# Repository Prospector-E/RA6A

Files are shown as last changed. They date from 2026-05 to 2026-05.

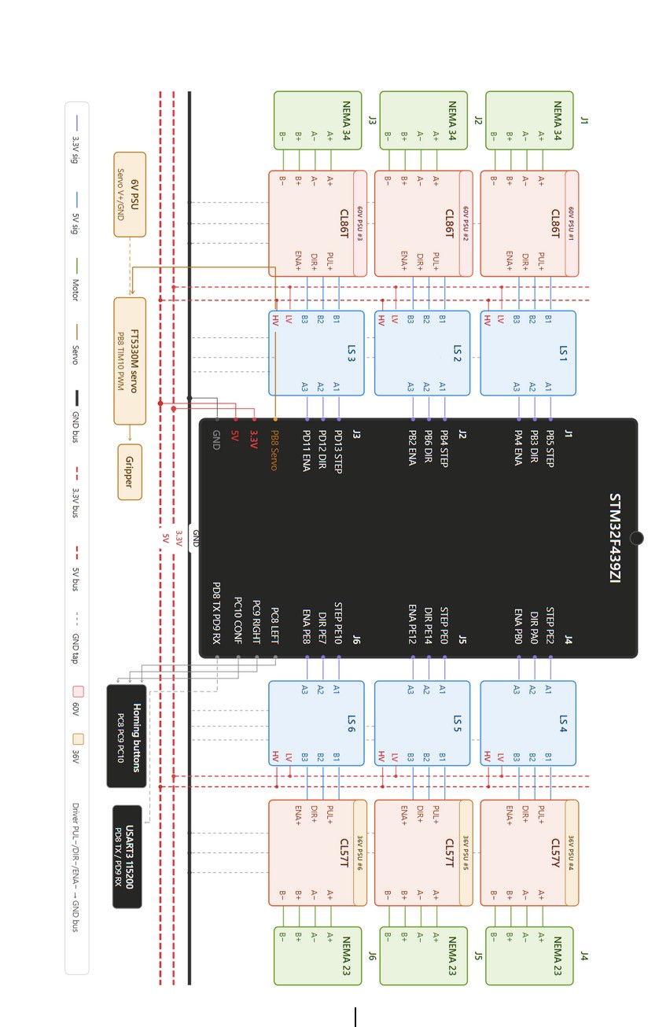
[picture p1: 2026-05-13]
images/wiring diagram.jpg

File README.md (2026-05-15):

# RA6A — 3D-Printed 6-Axis Robotic Arm

📺 **Demo:** https://youtu.be/l62hkhJTfqE?si=eneqJugdLhpxHiAf

Design, construction, and control of a 6-axis robotic arm built around an STM32F439ZI microcontroller and ROS 2 Humble with MoveIt 2. Capable of pick-and-place operation with vision-based cube detection.

Contact me if you have any questions, I’d love to see what the community does with this.

-----

## ⚠️ Important Warnings — Read Before Building

### CAD files are incomplete and contain errors

The STEP files in `hardware/cad/` are a **work-in-progress reference**, not a finished build package. If you intend to replicate this arm, be aware of the following:

- **Idler pulleys are not modeled** — every belt-driven joint requires idler pulleys for proper belt tensioning and routing. These are **mandatory** for the arm to function. You must add them yourself based on your motor placement and belt length.
- **Joint 2 (shoulder) deflects under load** — the J2 mechanical design is structurally weak and visibly deflects when the arm extends or carries payload. The cantilever geometry concentrates stress at the joint, and PLA+ creep makes it worse over time. A replicator should reinforce J2 with metal brackets, redesign the joint with a thicker cross-section, or use a co-axial drive configuration instead of the offset design used here. This is a known unresolved issue and one of the biggest weaknesses of the current design.
- **Belts are not modeled** — HTD-5M timing belts are used throughout. Lengths must be measured from your physical build.
- **Many small errors exist** — incorrect tolerances on some bearing pockets, hole misalignments, missing fillets, and a few non-printable overhangs. Expect to fix issues as you print.
- **The gripper is not my design** — it’s adapted from the AR4 open-source arm by Chris Annin (Annin Robotics). The original AR4 gripper files are available at https://www.anninrobotics.com — see the Acknowledgements section.

If you’re replicating this design, treat the CAD as a starting point — you will need to do your own engineering review and modifications.

### Hardcoded configuration to change

Before running anything, update these values for your setup:

- **iPhone camera IP** in the vision scripts (default `192.168.100.206` — your network will assign a different one)
- **Serial port** for the STM32 (default `/dev/ttyACM0` on Linux)
- **Camera calibration file path** in `scripts/aruco_detect.py` and `scripts/cube_detector_node.py`
- **ArUco marker positions** in `MARKER_POSITIONS_BASE` — these are measured from *my* workspace; you must re-measure them for yours (see the calibration section below)
- **Table height** — `TABLE_Z` is hardcoded to `0.273` m (the height of my table surface above the robot’s `base_link` origin). You must measure your own table height and update this value in `scripts/aruco_detect.py`, `scripts/cube_detector_node.py`, and `scripts/pick_and_place_vision.py`
- **Gripper length** — `GRASP_OFFSET` defaults to `0.10` m and is paired with a legacy fudge `Z_OFFSET_FIXED = -0.055` from my calibration. For a fresh build, **measure your real gripper length**, put that in `GRASP_OFFSET`, and set `Z_OFFSET_FIXED = 0`. See the Configuration section for details.
- **Gripper close angle** — `GRIP_CLOSE = 30` works for our 20 mm cubes and FT5330M servo. Different cubes or servos need recalibration; see the Configuration section.

-----

## Hardware Overview

|Component |Part |Notes |
|---|---|---|
|MCU |STM32F439ZI Nucleo-144 |Bare-metal firmware |
|J1–J3 motors |NEMA 34 stepper |High-torque base joints |
|J1–J3 drivers|CL86T closed-loop |60 V PSU each |
|J4–J6 motors |NEMA 23 stepper |Wrist joints |
|J4–J6 drivers|CL57T / CL57Y closed-loop|36 V PSU each |
|Gripper |FT5330M servo |**Adapted from AR4** — software PWM on PC11|
|Transmission |HTD-5M timing belts |Idler pulleys required (not in CAD) |
|Logic level  |3.3 V → 5 V shifter |Between STM32 and driver inputs |
|Structure |PLA+, 3D printed |Creality K2 Plus |

**Manual homing buttons:** LEFT (PC8), RIGHT (PC9), CONFIRM (PC10).

-----

## Software Architecture

```
┌─────────────────┐    plan trajectory    ┌────────────────────┐
│   MoveIt 2      │ ─────────────────────▶│  ra6a_hardware     │
│   (planning)    │                       │  (ROS 2 control)   │
└─────────────────┘                       └─────────┬──────────┘
                                                    │ 60 Hz serial
                                                    │ rosserial topics
                                                    ▼
                                          ┌─────────────────────┐
                                          │  STM32F439ZI        │
                                          │  - trapezoidal exec │
                                          │  - software PWM     │
                                          │  - manual homing    │
                                          └─────────────────────┘
```

MoveIt does all trajectory planning. The `ra6a_hardware` package forwards waypoints to the STM32 at 60 Hz over serial. The STM32 executes waypoints with trapezoidal velocity profiling and reports state back at 20 Hz.

**rosserial topic IDs:**

- `101` — joint command
- `102` — joint state feedback (20 Hz)
- `103` — homing complete
- `104` — motion complete
- `105` — gripper servo

-----

## Prerequisites

- Ubuntu 22.04 with ROS 2 Humble
- MoveIt 2 (`sudo apt install ros-humble-moveit`)
- `pick_ik` plugin (`sudo apt install ros-humble-pick-ik`)
- Python 3 with `opencv-python`, `numpy`, `pyserial`, `pyyaml`
- For firmware build: GCC ARM toolchain (`arm-none-eabi-gcc`), `make`
- DroidCam app on iPhone for vision pipeline (free version is enough)

-----

## Setup — Step by Step

### 1. Clone the repo

```bash
git clone https://github.com/Prospector-E/RA6A.git
cd RA6A
```

### 2. Build and flash STM32 firmware

The firmware is built with a Makefile — **no STM32CubeIDE required**.

```bash
cd firmware
make clean
make
```

This produces `build/ra6a.bin`. To flash, plug the Nucleo board into USB and copy the binary onto its mounted drive:

```bash
# Linux
cp build/ra6a.bin /media/$USER/NODE_F439ZI/

# Windows (in Git Bash)
cp build/ra6a.bin /x/      # replace /x/ with the Nucleo's drive letter
```

The board reflashes itself and resets automatically.

### 3. Build the ROS 2 workspace

```bash
cd ros2_ws
colcon build --symlink-install
source install/setup.bash
```

Add the source line to your `.bashrc` to avoid repeating it every terminal:

```bash
echo "source ~/RA6A/ros2_ws/install/setup.bash" >> ~/.bashrc
```

### 4. Update the serial port (if needed)

The STM32 typically appears as `/dev/ttyACM0`. Check with:

```bash
ls /dev/ttyACM*
```

If yours is different, update the `serial_port` parameter in `ros2_ws/src/ra6a_hardware/config/ra6a_hardware.yaml`.

Give your user permission to use serial without sudo:

```bash
sudo usermod -aG dialout $USER
# Log out and back in for it to take effect
```

-----

## Running the Arm

### 1. Manual homing (always first after power-up)

When the STM32 boots, all joints are at position zero in software but at arbitrary positions in reality. Home each joint manually:

1. Power on the arm.
1. Hold the **LEFT (PC8)** or **RIGHT (PC9)** button — the currently active joint moves in that direction.
1. Position the joint at its mechanical home reference.
1. Press **CONFIRM (PC10)** to save that position and advance to the next joint.
1. Repeat for all 6 joints.

Homed positions are saved to STM32 flash, so subsequent power-ups remember them. You only need to re-home if the arm is moved by hand or the flash is erased.

### 2. Launch MoveIt + hardware interface

```bash
ros2 launch ra6a_moveit_config servo.launch.py
```

This brings up MoveIt with the Servo plugin, RViz, and connects to the STM32 over serial. You should see the arm pose in RViz match the real arm.

### 3. Run pick-and-place

In a new terminal:

```bash
cd ~/RA6A/scripts
python3 pick_and_place_vision.py
```

The script runs the sequence: REST → PICK → grip → REST → PLACE → release → REST.

Edit the pick/place coordinates at the top of the script for your workspace.

-----

## Running the Vision Pipeline

The vision pipeline involves three calibration steps, done in this order:

1. **Camera intrinsics** — characterize the iPhone camera (lens distortion, focal length). One-time per camera.
1. **ArUco marker calibration** — tell the code where the table markers physically sit in the robot’s frame. Required for the camera-to-robot transform.
1. **Vision-to-arm calibration** — correct for residual systematic errors between detected cube positions and where the arm actually reaches. Optional but strongly recommended.

### 1. Set up DroidCam on iPhone

1. Install **DroidCam** from the App Store.
1. Connect the iPhone to the same WiFi as your Linux machine.
1. Open the app — note the IP address shown (e.g. `192.168.100.206`).
1. In settings, set resolution to 720p and lock exposure by tapping and holding on the workspace.

### 2. Update the IP in the scripts

The IP is hardcoded in three files (your iPhone’s IP will be different):

```bash
grep -rn "192.168" scripts/
```

Edit each file and change `IPHONE_IP = '192.168.100.206'` to your iPhone’s IP.

### 3. Camera intrinsics calibration (`calibrate_camera.py`)

This step measures the iPhone’s lens distortion and focal length using a printed checkerboard. The output is `camera_calibration.yaml`, which the detection scripts load. Done once per camera (or whenever you change cameras).

1. Print a checkerboard pattern on A4 paper. The defaults in the script are **9×6 inner corners** with **26 mm squares** — measure your printed squares and update `CHECKERBOARD` and `SQUARE_SIZE_M` constants if yours differ.
1. Tape it flat to a rigid board (so it doesn’t curl).
1. Run the script:
   
   ```bash
   python3 scripts/calibrate_camera.py
   ```
1. A live feed window opens. Hold the board in front of the iPhone — when the script detects the corners, they’re outlined in green.
1. Press **SPACE** to capture a frame. Capture 15–20 frames from different angles, distances, and positions (corners of frame, edges, close, far, tilted).
1. Press **Q** to compute and save `camera_calibration.yaml`.
1. Update `CALIB_FILE` paths in `aruco_detect.py` and `cube_detector_node.py` to point to wherever you saved it.

### 4. ArUco marker calibration (manual — must be done for your workspace)

The vision pipeline locates the iPhone camera in the robot’s frame by detecting four printed ArUco markers placed at known positions on the table. **You must physically measure each marker’s position relative to the robot’s `base_link` and update the code.** There is no automated procedure — this is a manual measurement step.

**Robot frame convention (`base_link`):**

- Origin is at the center of the robot’s base, on the bottom mounting surface
- **+X axis** points to the back of the robot (away from the front face)
- **+Y axis** points to the right (when standing behind the robot)
- **+Z axis** points up

**Setup procedure:**

1. **Print four ArUco markers**, **50 mm** each, with IDs **0, 1, 2, 3**. Use the same dictionary the code expects — check the `ARUCO_DICT` constant in `aruco_detect.py` (default `DICT_4X4_50`).
1. **Stick them flat on your table surface** at the corners of the workspace. They must be:
- **Flat** (no curling or tilt — back them with cardboard or stick to a rigid surface)
- **Visible to the iPhone camera** at all times
- **Spread out** (the further apart, the more accurate the camera pose solve)
- **Oriented consistently** — all four markers’ “up” direction the same way. This matters for the manual-corner calibration mode (see below).
1. **Measure the table height.** With a ruler or caliper, measure from the bottom of the robot’s base plate (the `base_link` origin Z = 0 plane) up to the top of the table surface. Record this value in **meters**. Example: 27.3 cm above the base → `TABLE_Z = 0.273`.
1. **Measure each marker’s center position** in the robot frame:
- Measure X (back/forward) and Y (right/left) of each marker’s center from the robot base origin.
- Z is the same as `TABLE_Z` for all four (they’re all on the table surface).
- Use **meters with signs**. Markers in front of the robot have negative X. Markers to the left of the robot have negative Y.
- Tip: stick a piece of tape on the table aligned with the robot’s center, run another tape strip out from the base for the X axis, and measure offsets from there.
1. **Update the constants** in both `scripts/aruco_detect.py` and `scripts/cube_detector_node.py`:
   
   ```python
   TABLE_Z = 0.273   # ← your measured table height (meters)
   
   MARKER_POSITIONS_BASE = {
       3: np.array([-0.370,  0.164, TABLE_Z]),   # ← your measured X, Y for marker 3
       2: np.array([-0.370, -0.268, TABLE_Z]),   # ← marker 2
       1: np.array([-0.190,  0.164, TABLE_Z]),   # ← marker 1
       0: np.array([-0.190, -0.268, TABLE_Z]),   # ← marker 0
   }
   ```
1. **Update the workspace bounds** in both files to match the rectangle bounded by your marker centres:
   
   ```python
   WORKSPACE_X_MIN, WORKSPACE_X_MAX = -0.370, -0.190    # min/max of marker X
   WORKSPACE_Y_MIN, WORKSPACE_Y_MAX = -0.268, +0.164    # min/max of marker Y
   ```
1. **Verify visually.** Run `python3 scripts/aruco_detect.py` — you should see the markers detected (green outlines) and the yellow workspace rectangle drawn on the table with its corners at the marker centres. Place a cube at a measured spot and check that the script’s reported position matches your ruler. If they disagree, your marker positions or `TABLE_Z` are off — re-measure.
1. **If your lighting is poor and ArUco auto-decode is flaky** — press `k` in the viewer and click each marker’s 4 corners (CW from each marker’s top-left, 16 clicks total). This saves to `~/manual_marker_corners.json` and the detector falls back to your manual corners whenever auto-decode fails. See the Configuration section below for full hotkey reference.

**Why this matters:** a 5 mm measurement error on a marker translates into noticeable end-effector offsets during pick attempts. Don’t eyeball it. Use a hard ruler or caliper and double-check signs.

### 5. Vision-to-arm calibration (`calibrate_vision.py`)

Even after camera intrinsics and ArUco calibration are done correctly, the position the camera reports for a cube and the position the arm actually reaches may still differ by a few millimeters or a small rotation, due to camera mount imperfection, base-frame misalignment, or small ArUco measurement errors. This script computes a 2D affine transform from “detected” to “real” coordinates and saves it to `~/vision_calibration.json`. The `pick_and_place_vision.py` script automatically loads and applies this transform.

**Strongly recommended.** Skipping this step usually results in pick attempts missing the cube by a few centimeters.

**Procedure:**

1. Place **three cubes** of different colors anywhere in the workspace (spread them out — corners of the workspace work best).
1. Start the supporting nodes in two separate terminals:
   
   ```bash
   # Terminal 1
   ros2 launch ra6a_moveit_config servo.launch.py
   
   # Terminal 2
   python3 scripts/cube_detector_node.py
   ```
1. In a third terminal, run the calibration script:
   
   ```bash
   python3 scripts/calibrate_vision.py
   ```
1. For each of the three cubes, the script prompts you to position the gripper:
- Use RViz’s interactive marker (plan + execute) to move the gripper **directly above the cube center**
- Gripper should point **straight down**
- Tip of the gripper jaws should be roughly **10 cm above the cube top**
- When the gripper is in position, press **SPACE** in the calibration terminal to record the pair (detected position, actual position)
1. After three pairs are recorded, the script computes the transform and saves `~/vision_calibration.json`. Done.
1. **Re-run this calibration whenever:**
- The iPhone is repositioned or remounted
- The robot is moved relative to the table
- The ArUco markers are repositioned
- Pick attempts start consistently missing in a systematic direction

### 6. Run vision-based pick-and-place

```bash
# Terminal 1: MoveIt + hardware
ros2 launch ra6a_moveit_config servo.launch.py

# Terminal 2: cube detector
python3 scripts/cube_detector_node.py

# Terminal 3: pick-and-place driver
python3 scripts/pick_and_place_vision.py
```

-----

## Configuration Variables and Tuning

This section is a reference for every tunable knob in the pipeline. Variables you *must* set for your hardware (table height, marker positions, camera IP) were covered above in workflow style; this section covers the rest — gripper geometry, servo angles, cube size, persisted JSON files, and viewer hotkeys.

### Gripper geometry — match these to your physical gripper

Set in `scripts/pick_and_place_vision.py`:

|Variable |Default |What it is |
|---|---|---|
|`GRASP_OFFSET`  |`0.10` m  |Distance from your URDF’s `end_effector` frame down to the grasp point (centre between closed jaws). Measure with a ruler. |
|`Z_OFFSET_FIXED`|`-0.055` m|Legacy fudge from my own calibration. **For a fresh build, leave this at `0` and just put your real measured gripper length in `GRASP_OFFSET`.** The grasp height equation is `TABLE_Z + CUBE_HEIGHT/2 + GRASP_OFFSET + Z_OFFSET_FIXED + GRASP_Z_ADJUST`, so the two `Z_OFFSET*` terms sum to your effective gripper length. Cleaner to use just one.|
|`GRASP_Z_ADJUST`|`+0.005` m|Fine-tune knob. Positive lifts the grip a bit higher (less risk of scraping the table); negative pushes deeper. Adjust in 1 mm steps after the rest is set. |
|`CUBE_HEIGHT` |`0.020` m |Edge length of your cubes. Used for both grasp height and to project the colour silhouette to mid-cube height. Change if your cubes aren’t 20 mm. |

### Gripper servo angles — calibrate to avoid stall

For servos with built-in overload/stall protection (e.g. FT5330M), you **cannot** command `GRIP_CLOSE = 0` on a cube that’s smaller than the gripper’s maximum closure. The servo will try, hit the cube, detect overcurrent, and back off — and your cube falls.

Set in `scripts/pick_and_place_vision.py`:

```python
GRIP_OPEN = 90      # fully open — usually fine at 90 for FT5330M-like servos
GRIP_CLOSE = 30     # just enough to grip your cube without stalling
```

**To calibrate `GRIP_CLOSE`:** start at `35`. Try a pick. If the cube wobbles or slides, lower to `30`. If you can hear the servo cycling or buzzing, back off by `5`. The right value is the *highest* one that still firmly holds the cube — stay above the stall threshold.

Different cube sizes need different `GRIP_CLOSE` values. If you change cube size, recalibrate.

### Persisted calibration files — saved per-user, auto-loaded

Three JSON files live in your home directory. They’re created at runtime during calibration in `aruco_detect.py` and `calibrate_vision.py`, then auto-loaded by the detector node and pick script:

|File |Created by |Loaded by |What it stores |
|---|---|---|---|
|`~/manual_marker_corners.json`|viewer, press `k` then click |viewer + detector node |The 16 corner-pixel positions of the 4 ArUco markers, for hybrid pose solving when auto-decode fails (low light, motion blur).|
|`~/color_thresholds.json` |viewer, press `R`/`G`/`B`/`Y` then `1`–`4`|viewer + detector node |HSV `S_min` and `V_min` thresholds for each cube colour. Saved on every key press so the latest values always carry over. |
|`~/vision_calibration.json` |`calibrate_vision.py` |`pick_and_place_vision.py`|2D affine transform `(A, b)` correcting vision xy to arm xy. See section 5 above. |

Delete any of these to force a fresh calibration on next run.

### `aruco_detect.py` viewer — full hotkey reference

The diagnostic viewer is your main tuning tool. Run it before the node to dial in calibration without launching the whole pipeline.

```bash
python3 scripts/aruco_detect.py
```

**Display toggles:**

- `q` — quit
- `c` — toggle CLAHE preprocessing (adaptive contrast; helps with uneven light)
- `m` — toggle the 4-panel colour mask window
- `r` — toggle the adaptive-threshold window (shows what ArUco’s decoder sees)
- `+` / `-` — increase / decrease CLAHE clip limit
- `s` — save a snapshot of the current view

**Pose helpers:**

- `L` — lock the current pose. Useful when ArUco briefly decodes all 4 markers in good light — lock that pose and use it for the session even if lighting changes.
- `U` — unlock and resume normal detection.
- `k` — calibrate ALL markers (16 clicks: 4 corners CW for each of M0, M1, M2, M3).
- `e` then `0`/`1`/`2`/`3` — redo a SINGLE marker (4 clicks). Use when one marker came out misaligned without redoing the others.
- `K` — clear manual calibration (deletes `~/manual_marker_corners.json`).

**Colour tuning:**

- `R` / `G` / `B` / `Y` (Shift held) — select which colour the 1-4 keys adjust. Current selection shown in the overlay.
- `1` / `2` — decrease / increase `S_min` for the selected colour.
- `3` / `4` — decrease / increase `V_min` for the selected colour.
- Left-click anywhere — sample HSV at that pixel (printed to console).

**Calibration workflow with the viewer:**

1. Set up the table, markers, and cubes in their final positions.
1. Run `aruco_detect.py`.
1. Sample HSV by clicking on each cube. Note the values.
1. Press `R` (or `G`/`B`/`Y`) for each colour, dial S_min and V_min to bracket the cube’s sample on the safe side.
1. Press `k`, do the 16-click marker calibration. Look for misalignments in the projected yellow workspace polygon; press `e` + marker index to redo just that one if needed.
1. Done — both `~/color_thresholds.json` and `~/manual_marker_corners.json` are written. The detector node will pick them up automatically on its next launch.

### Quick checklist for a fresh build

1. Calibrate camera intrinsics → `camera_calibration.yaml`; set `CALIB_FILE`.
1. Place ArUco markers, measure their xy → update `MARKER_POSITIONS_BASE`.
1. Measure table height → update `TABLE_Z` in all three vision scripts (and the z entries in `MARKER_POSITIONS_BASE`).
1. Measure your gripper length → set `GRASP_OFFSET`, leave `Z_OFFSET_FIXED = 0`.
1. Update workspace bounds to match marker xy range.
1. Set `GRIP_OPEN`/`GRIP_CLOSE` for your servo + cube size.
1. Run `aruco_detect.py` → manual marker calibration (`k`) → colour tuning (`R`/`G`/`B`/`Y` + `1`–`4`).
1. Run `calibrate_vision.py` for the 3-cube affine correction.
1. Launch the full pipeline; test one pick. If it misses low or high, nudge `GRASP_Z_ADJUST` by 1–2 mm.

-----

## Repository Structure

```
RA6A/
├── README.md                   You are here
├── firmware/                   STM32 bare-metal C
│   ├── Core/                   Application code
│   ├── Drivers/                STM32 HAL
│   ├── Makefile                Build with `make`
│   └── *.ld                    Linker scripts
├── ros2_ws/src/
│   ├── ra6a_hardware/          ros2_control hardware interface
│   ├── ra6a_moveit_config/     MoveIt config + launch files
│   └── ra6a_description/       URDF, meshes, SRDF
├── scripts/                    Python control + vision
│   ├── pick_and_place_vision.py
│   ├── aruco_detect.py
│   ├── cube_detector_node.py
│   ├── calibrate_camera.py     Checkerboard intrinsics
│   └── calibrate_vision.py     3-cube affine transform
├── hardware/
│   ├── cad/                    STEP files (⚠️ incomplete — see warnings)
│   ├── stl/                    STL exports
│   └── schematics/             Wiring diagrams
└── docs/
    └── images/                 Photos and diagrams
```

-----

## Known Issues and Limitations

- **CAD is incomplete** — see warnings at the top of this README.
- **J2 structural deflection** — the shoulder joint deflects under load and is the weakest link in the arm. The joint design should be reinforced or redesigned for higher-accuracy work. This single issue limits the overall achievable precision more than anything else.
- **Open-loop steppers** — no joint encoders, so position drift can occur if the arm hits hard limits. Re-home if motion becomes inaccurate.
- **Real-time teleop is jittery** — the current architecture is optimized for planned trajectories, not continuous streaming. Pick-and-place works smoothly; live teleop does not.
- **Singularities near vertical** — if the target pose is directly above the base, joint 5 reaches a singularity. Pre-rotate joint 1 to approach from an angle.
- **WiFi-dependent camera** — vision pipeline relies on DroidCam over WiFi. Network drops will pause detection.
- **ArUco calibration is manual** — there is no automated camera-to-robot calibration. Marker positions and table height must be physically measured and hardcoded into the scripts.
- **Vision calibration must be re-run** whenever the camera, robot, or markers are moved relative to each other.
- **Per-user calibration files** — the JSON files in `~/` (`manual_marker_corners.json`, `color_thresholds.json`, `vision_calibration.json`) are tied to the user account, not the repo. If you switch users or reinstall, you’ll need to redo the in-app calibration steps.
- **Stall-protection servos** — gripper servos with built-in current limiting (like the FT5330M used here) will drop the cube if commanded to close past its physical extent. `GRIP_CLOSE` must be tuned to stop just inside the cube width.

-----

## Acknowledgements

This project builds on existing open-source work. In particular:

- **Gripper design** — adapted from the **AR4** open-source 6-axis robotic arm by **Chris Annin** (Annin Robotics). The original mechanical design and the dual position-and-velocity interface concept were influential in this project’s architecture. Source: https://www.anninrobotics.com and https://github.com/ycheng517/ar4_ros_driver
- **MoveIt 2** — the entire motion planning stack
- **ROS 2 Humble** and the `ros2_control` framework

If you replicate the gripper, please credit Chris Annin / Annin Robotics in your own documentation.

-----

## License

Released under the MIT License. CAD files are provided as-is with no warranty of fitness for any purpose (see warnings above). The gripper design is adapted from AR4 (Annin Robotics) — see Acknowledgements; please honor the original project’s licensing terms when redistributing gripper-related files.

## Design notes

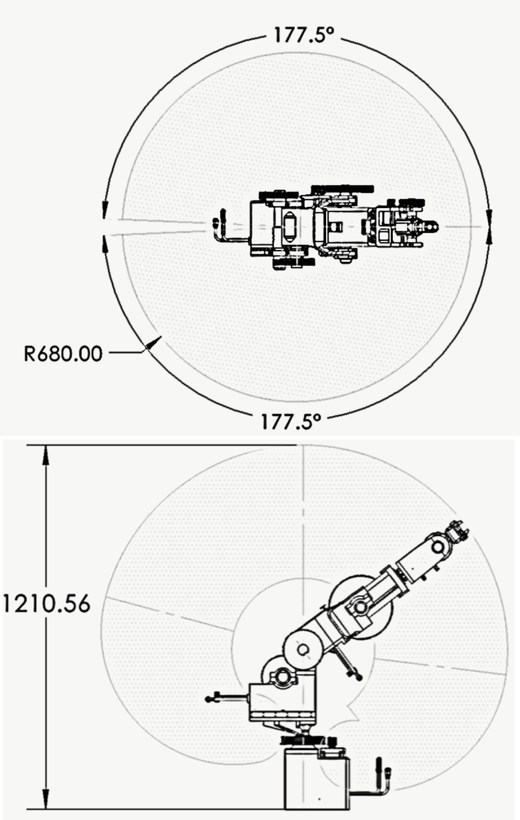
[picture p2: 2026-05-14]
images/workspace.jpeg

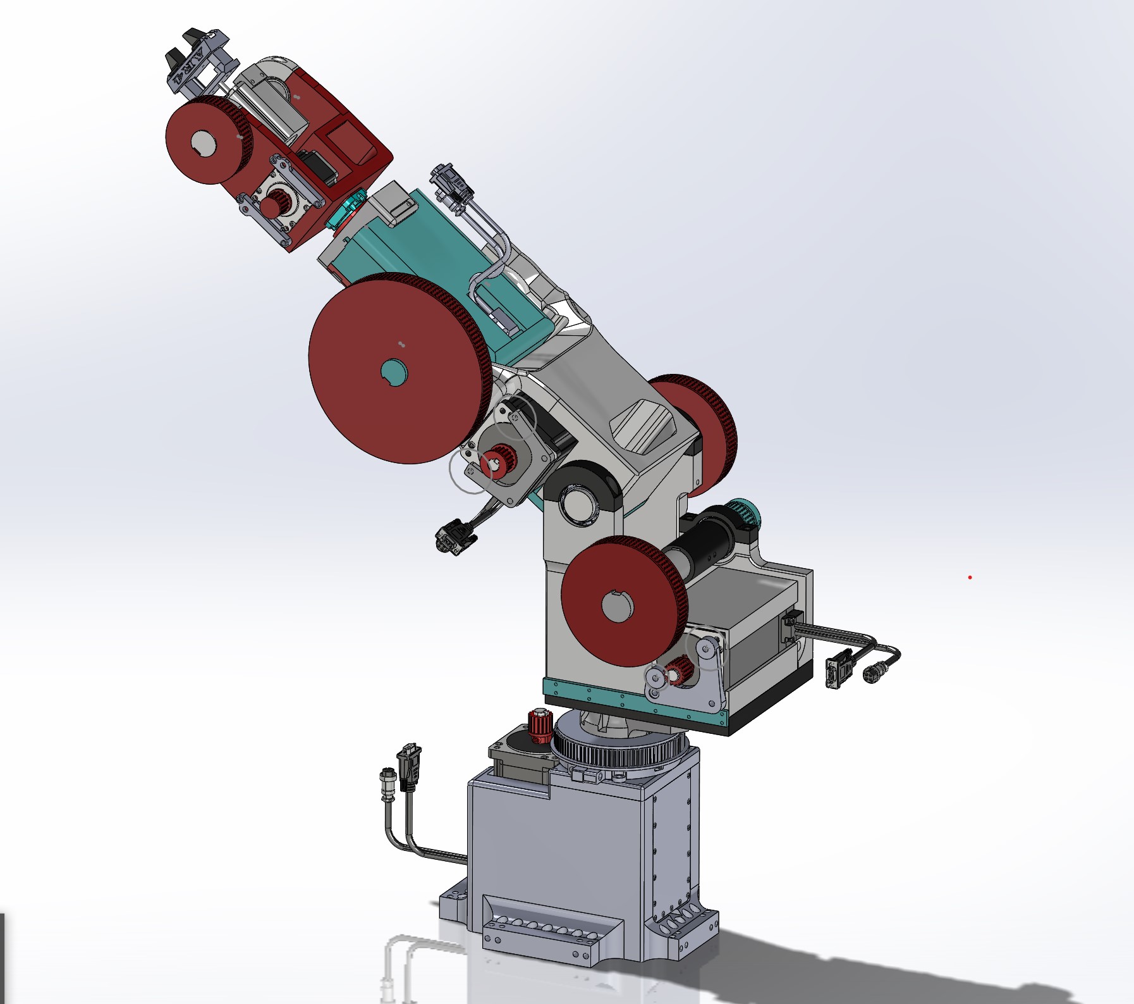
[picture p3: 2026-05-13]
images/CAD_screenshot.jpg

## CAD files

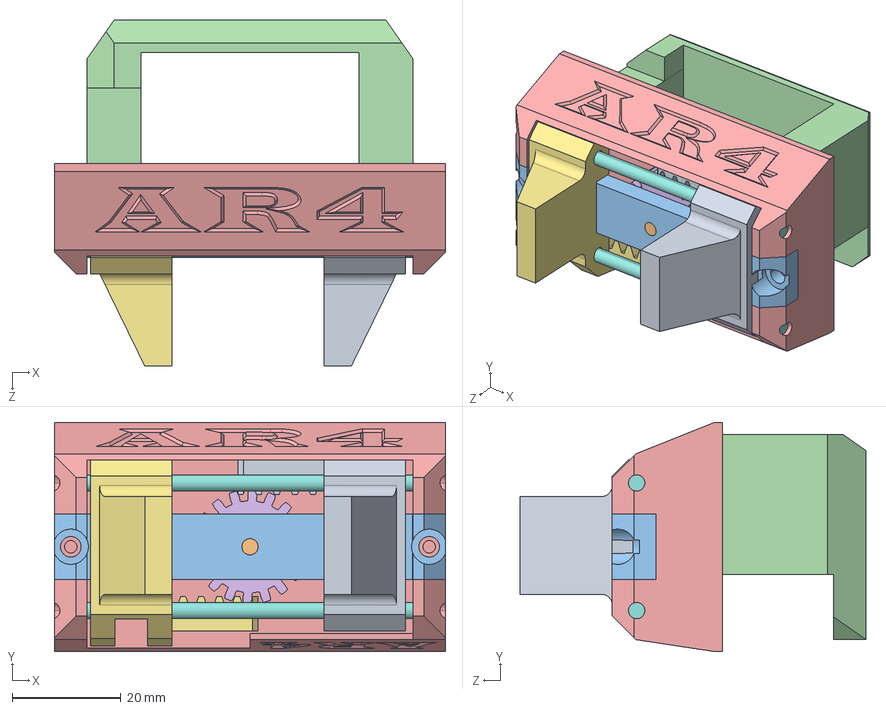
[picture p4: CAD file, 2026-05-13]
hardware/cad/AR4_SG1_assembly.STEP
72.0 x 42.2 x 63.7 mm
AR4_SG1_jaw2_As Machined
AR4_SG1_16.5_gear_rod_As Machined
AR4_SG1_center_bar_As Machined
AR4_SG1_base
AR4_SG1_carriage
AR4_SG1_gear_As Machined
AR4_SG1_jaw1_As Machined
AR4_SG1_70mm_carriage_rod_As Machined x 2

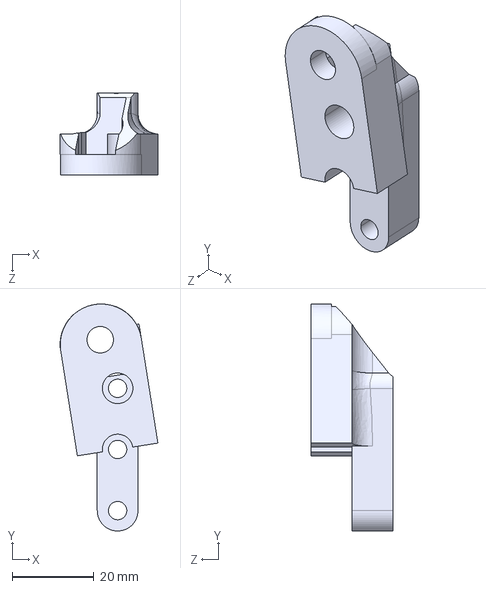
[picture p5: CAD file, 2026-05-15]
hardware/cad/j2-2.STEP
24.0 x 55.7 x 20.0 mm

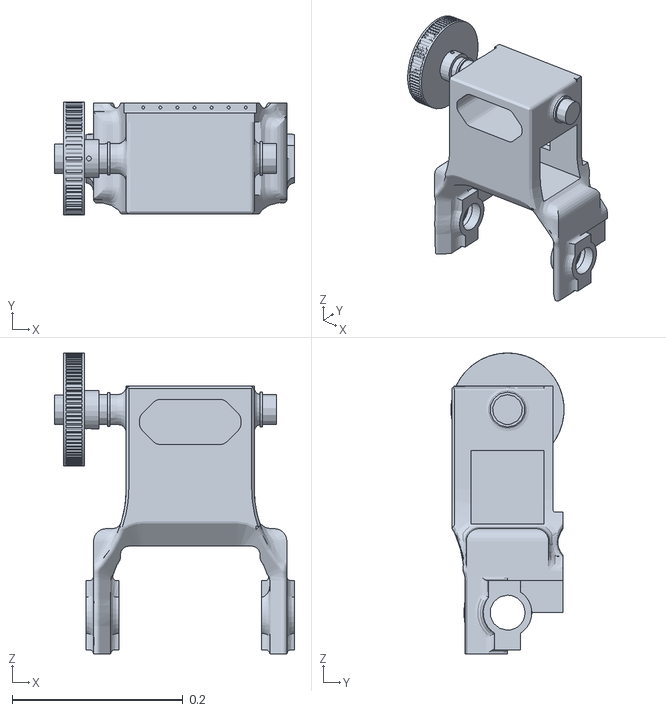
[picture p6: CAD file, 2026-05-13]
ros2_ws/src/ra6a/meshes/l2.stl
0.282 x 0.132 x 0.353

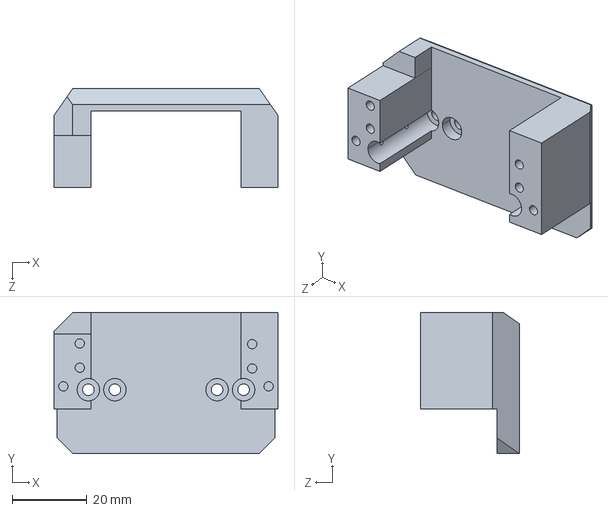
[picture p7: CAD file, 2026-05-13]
hardware/cad/AR4_SG1_base.STEP
60.0 x 37.8 x 26.4 mm

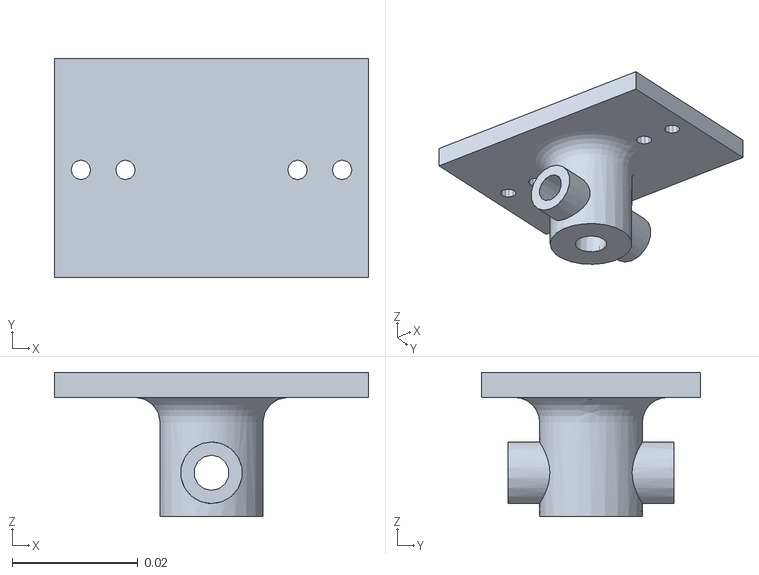
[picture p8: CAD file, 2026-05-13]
ros2_ws/src/ra6a/meshes/end_effector.stl
0.05 x 0.0348 x 0.023

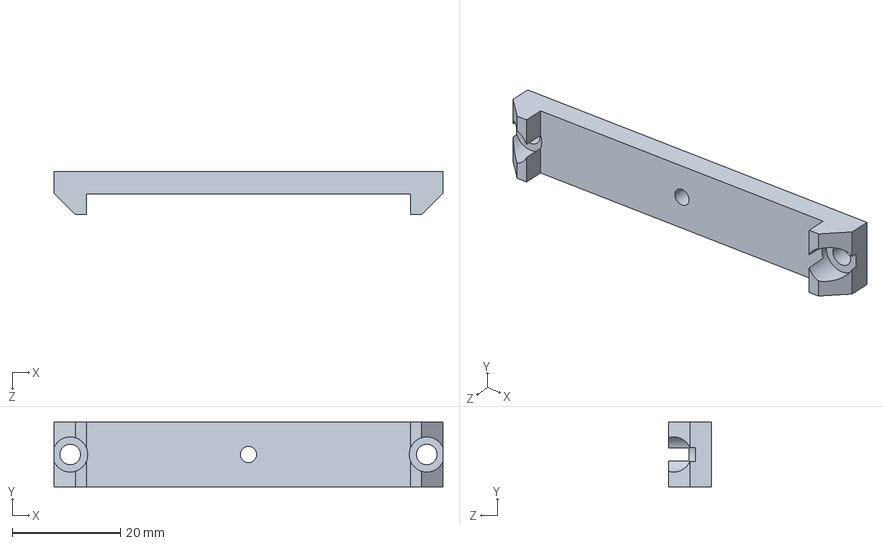
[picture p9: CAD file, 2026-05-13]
hardware/cad/AR4_SG1_center_bar.STEP
72.0 x 12.0 x 8.02 mm

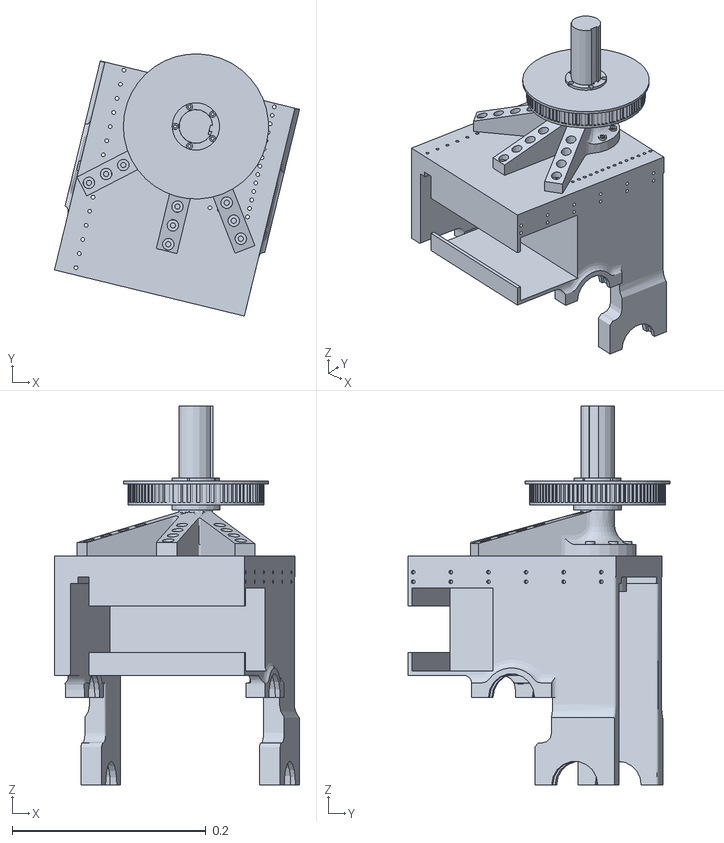
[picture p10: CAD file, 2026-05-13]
ros2_ws/src/ra6a/meshes/l1.stl
0.253 x 0.271 x 0.392

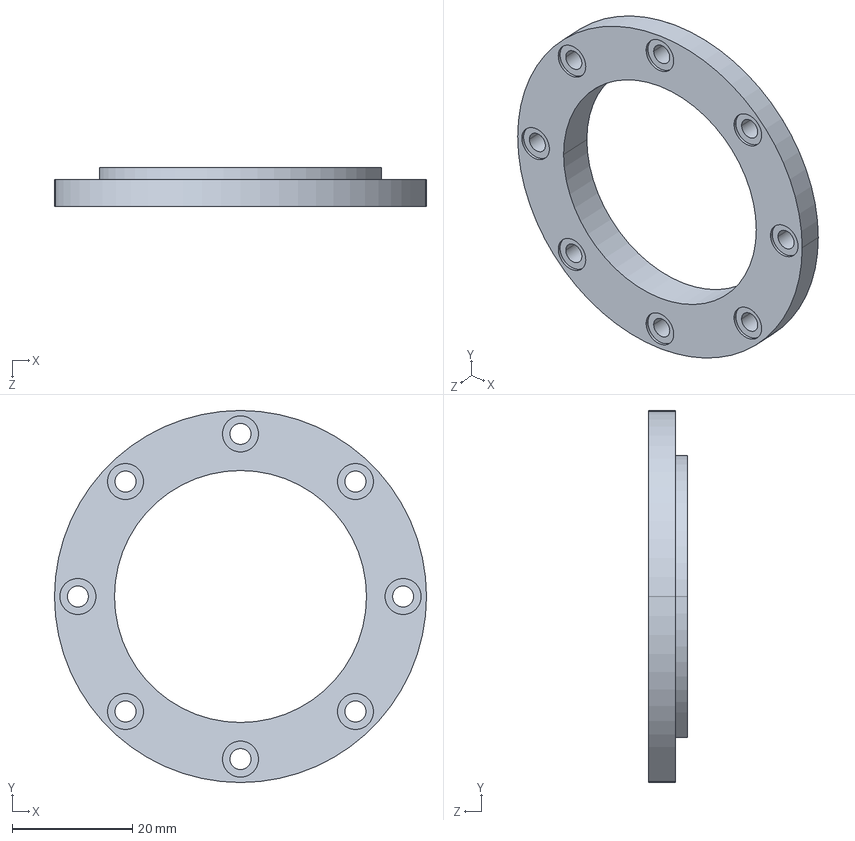
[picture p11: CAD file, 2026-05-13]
hardware/cad/L21-L22-bearing-fix.STEP
62.0 x 62.0 x 6.50 mm

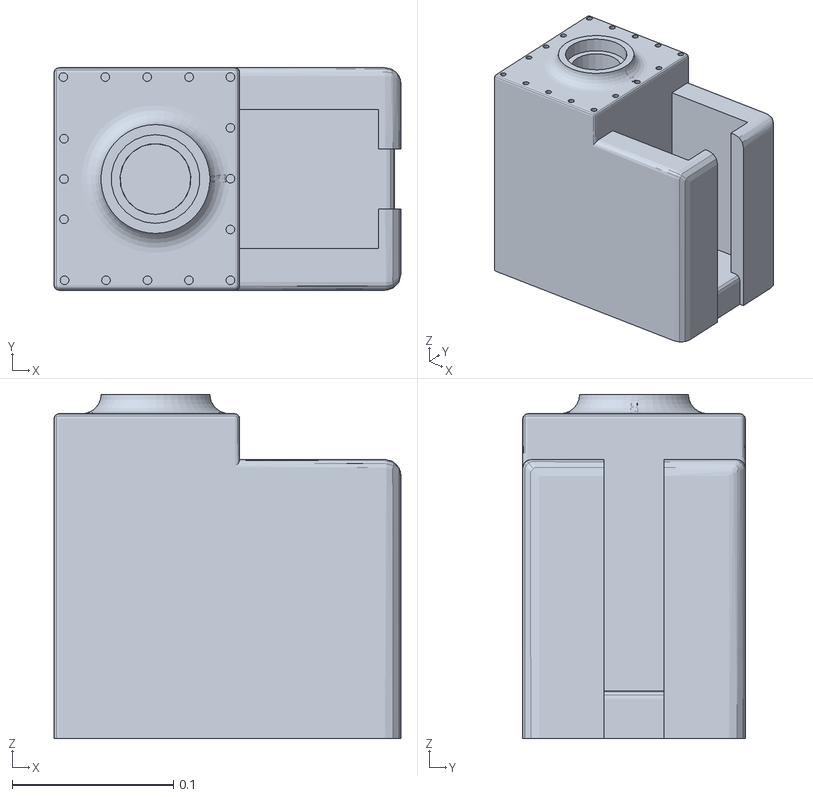
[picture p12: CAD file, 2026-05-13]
ros2_ws/src/ra6a/meshes/base_link.stl
0.215 x 0.138 x 0.214

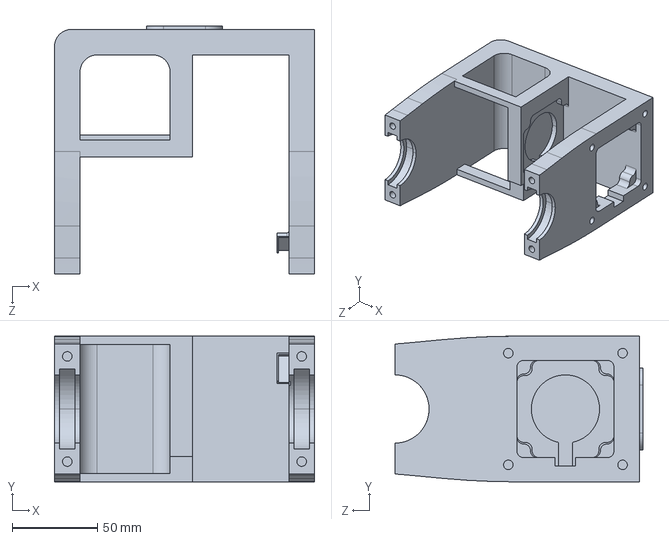
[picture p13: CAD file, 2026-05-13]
hardware/cad/L22 start new 3.STEP
152.5 x 85.5 x 145.5 mm

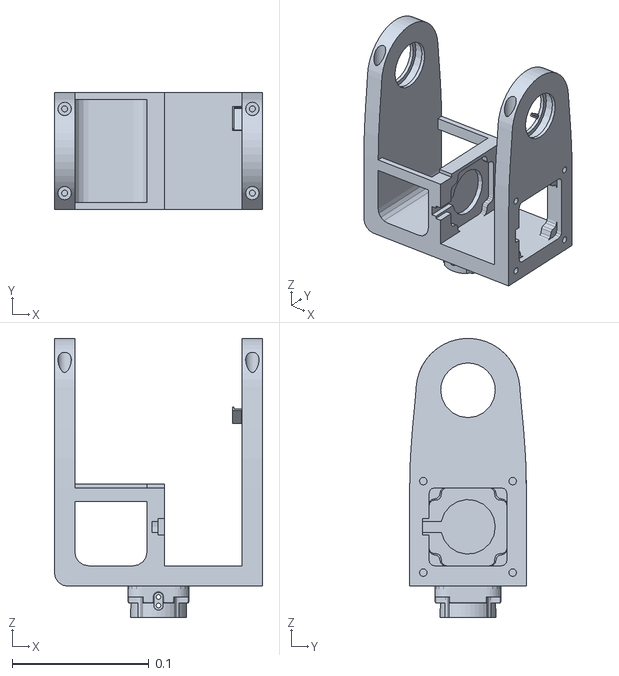
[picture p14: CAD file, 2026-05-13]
ros2_ws/src/ra6a/meshes/l4.stl
0.153 x 0.0855 x 0.204

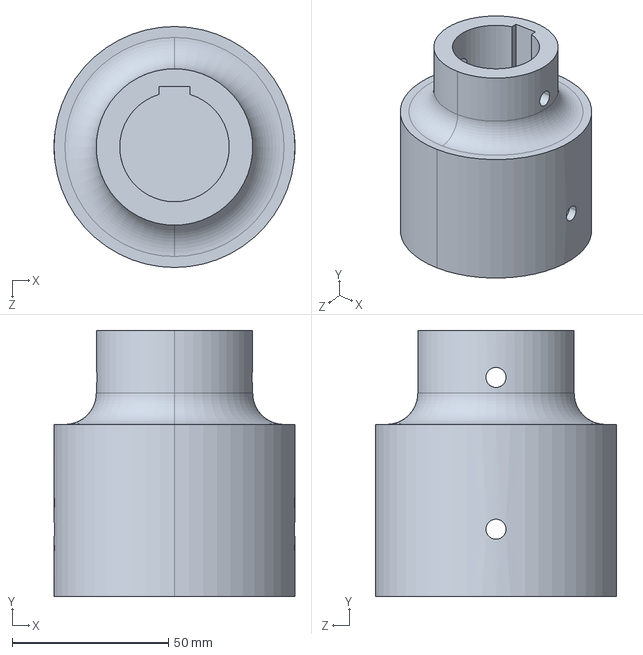
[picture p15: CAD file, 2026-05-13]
hardware/cad/shaft-baseV2-coupler.STEP
77.0 x 85.0 x 77.0 mm

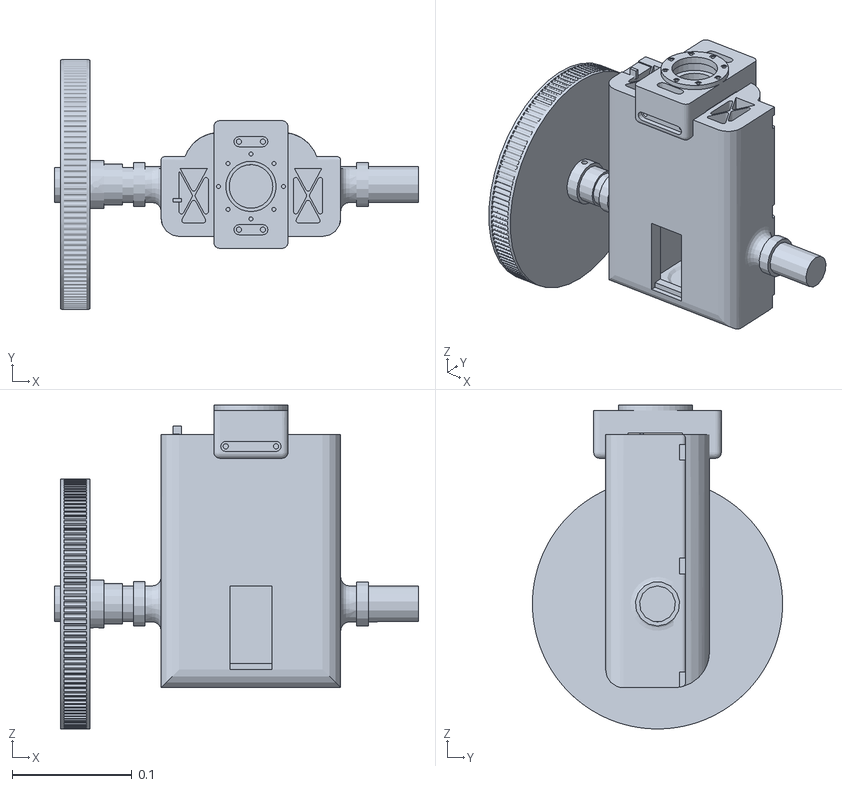
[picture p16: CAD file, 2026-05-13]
ros2_ws/src/ra6a/meshes/l3.stl
0.304 x 0.209 x 0.271

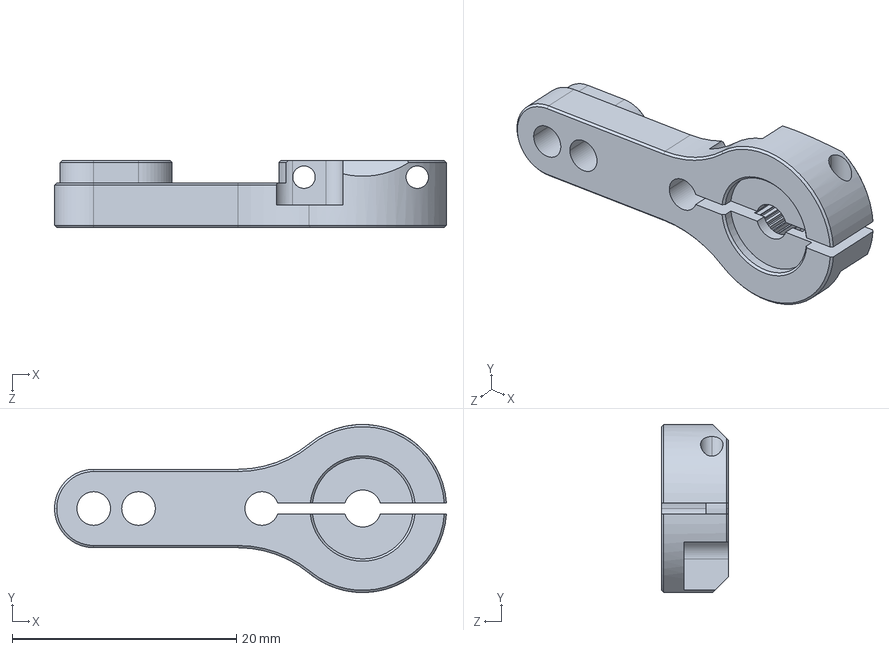
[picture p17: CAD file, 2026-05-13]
hardware/cad/Servo Arm.STEP
35.0 x 15.0 x 6.00 mm

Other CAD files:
ros2_ws/src/ra6a/meshes/l5.stl
hardware/cad/L1.STEP
hardware/cad/L21 Top New.STEP
hardware/cad/pulley 2 rotabase.STEP
hardware/cad/23HS30-2804-ME1K.STEP
hardware/cad/60T L22 1.STEP
hardware/cad/6656K153_Steel Ball Bearing.STEP
hardware/cad/6906 ball bearing.STEP
hardware/cad/6907 ball bearing.STEP
hardware/cad/AR4_SG1_16.5_gear_rod.STEP
hardware/cad/AR4_SG1_70mm_carriage_rod.STEP
hardware/cad/AR4_SG1_carriage.STEP
hardware/cad/AR4_SG1_gear.STEP
hardware/cad/AR4_SG1_jaw1.STEP
hardware/cad/AR4_SG1_jaw2.STEP
hardware/cad/EG23-G10-D8.STEP
hardware/cad/L1 bh1 LH.STEP
hardware/cad/L1 bh1.STEP
hardware/cad/L1 cover.STEP
hardware/cad/L1 pulley 1.STEP
hardware/cad/L2 St holder 1.STEP
hardware/cad/L2 pulley.STEP
hardware/cad/L21 bottom2022.STEP
hardware/cad/L21-L22-shaft-2.STEP
hardware/cad/L21-L22-shaft.STEP
hardware/cad/L22 start new Bearing cover.STEP
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

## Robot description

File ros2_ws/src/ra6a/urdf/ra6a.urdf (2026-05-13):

<?xml version="1.0" encoding="utf-8"?>
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
<robot name="ra6a">
  <link name="base_link">
    <inertial>
      <origin xyz="0.039204 -6.6862E-07 -0.010842" rpy="0 0 0" />
      <mass value="2.915" />
      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
    </inertial>
    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
  </link>
  <link name="l1">
    <inertial>
      <origin xyz="-0.018341 -0.038699 -0.09919" rpy="0 0 0" />
      <mass value="2.4989" />
      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
    </inertial>
    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
  </link>
  <joint name="j1" type="revolute">
    <origin xyz="0 0 0.1369" rpy="3.1416 0 4.473940413" />
    <parent link="base_link" />
    <child link="l1" />
    <axis xyz="0 0 1" />
    <limit lower="-3.0979" upper="3.0979" effort="55.5" velocity="1.05" />
  </joint>
  <link name="l2">
    <inertial>
      <origin xyz="-0.023045 -0.0039604 -0.089257" rpy="0 0 0" />
      <mass value="3.5609" />
      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
    </inertial>
    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
  </link>
  <joint name="j2" type="revolute">
    <origin xyz="0 0 -0.2922" rpy="0 0 -0.23845" />
    <parent link="l1" />
    <child link="l2" />
    <axis xyz="1 0 0" />
    <limit lower="-1.30899694" upper="1.69296937" effort="110" velocity="1.05" />
  </joint>
  <link name="l3">
    <inertial>
      <origin xyz="-0.049486 -0.00089697 0.024" rpy="0 0 0" />
      <mass value="3.1038" />
      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
    </inertial>
    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
  </link>
  <joint name="j3" type="revolute">
    <origin xyz="0 0 -0.23789" rpy="1.5708 0 -3.1416" />
    <parent link="l2" />
    <child link="l3" />
    <axis xyz="1 0 0" />
    <limit lower="-0.4363323" upper="3.577925" effort="65" velocity="1.05" />
  </joint>
  <link name="l4">
    <inertial>
      <origin xyz="-0.00644648015582011 0.00019408303741475 0.0542634295034519" rpy="0 0 0" />
      <mass value="0.72283" />
      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
    </inertial>
    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
  </link>
  <joint name="j4" type="revolute">
    <origin xyz="5.5E-05 -0.0016053 0.1825" rpy="0 0 0" />
    <parent link="l3" />
    <child link="l4" />
    <axis xyz="0 0 1" />
    <limit lower="-3.0979" upper="3.0979" effort="20" velocity="1.05" />
  </joint>
  <link name="l5">
    <inertial>
      <origin xyz="0.033993520449142 0.000239344637752714 -0.0069745494687703" rpy="0 0 0" />
      <mass value="0.59888" />
      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
    </inertial>
    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
  </link>
  <joint name="j5" type="revolute">
    <origin xyz="0 0 0.1435" rpy="0 0 0" />
    <parent link="l4" />
    <child link="l5" />
    <axis xyz="1 0 0" />
    <limit lower="-1.5708" upper="1.5708" effort="7" velocity="1.05" />
  </joint>
  <link name="end_effector">
    <inertial>
      <origin xyz="1.08576461155252E-08 3.29977418729588E-06 -0.00208152036490139" rpy="0 0 0" />
      <mass value="0.010728" />
      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
    </inertial>
    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
  </link>
  <joint name="j6" type="revolute">
    <origin xyz="0 0 0.048" rpy="0 0 0" />
    <parent link="l5" />
    <child link="end_effector" />
    <axis xyz="0 0 1" />
    <limit lower="-3.0979" upper="3.0979" effort="1.8" velocity="1.05" />
  </joint>

  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
  <ros2_control name="ra6a_system" type="system">
    <hardware>
      <plugin>ra6a_hardware/Ra6aSystem</plugin>
      
      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
      <param name="mode">real</param>
      
      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
      <param name="serial_port">/dev/ttyACM0</param>
      <param name="baud_rate">115200</param>
    </hardware>

    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
    <joint name="j1">
<command_interface name="position"/>

<state_interface name="position"/>
<state_interface name="velocity"/>

    </joint>

    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
    <joint name="j2">
 <command_interface name="position"/>


<state_interface name="position"/>
<state_interface name="velocity"/>

    </joint>

    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
    <joint name="j3">
 <command_interface name="position"/>


<state_interface name="position"/>
<state_interface name="velocity"/>

    </joint>

    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
    <joint name="j4">
 <command_interface name="position"/>

<state_interface name="position"/>
<state_interface name="velocity"/>

    </joint>

    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
    <joint name="j5">
   <command_interface name="position"/>

<state_interface name="position"/>
<state_interface name="velocity"/>

    </joint>

    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
    <joint name="j6">
      <command_interface name="position"/>

<state_interface name="position"/>
<state_interface name="velocity"/>

    </joint>
    
  </ros2_control>

</robot>

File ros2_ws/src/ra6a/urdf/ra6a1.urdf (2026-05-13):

<?xml version="1.0" encoding="utf-8"?>
<!-- This URDF was automatically created by SolidWorks to URDF Exporter! Originally created by Stephen Brawner (brawner@gmail.com) 
     Commit Version: 1.6.0-4-g7f85cfe  Build Version: 1.6.7995.38578
     For more information, please see http://wiki.ros.org/sw_urdf_exporter -->
<robot name="ra6a">
  <link name="base_link">
    <inertial>
      <origin xyz="0 0 0" rpy="0 0 0" />
      <mass value="2.915" />
      <inertia ixx="0.01436" ixy="-9.7839E-06" ixz="8.8797E-08" iyy="0.016743" iyz="-8.9882E-08" izz="0.017881" />
    </inertial>
    <visual>
      <origin xyz="0 0 0" rpy="0 0 0" />
      <geometry>
        <mesh filename="package://ra6a/meshes/base_link.stl" scale="1.0 1.0 1.0"/>
      </geometry>
      <material name="">
        <color rgba="1 1 1 1" />
      </material>
    </visual>
    <collision>
      <origin xyz="0 0 0" rpy="0 0 0" />
      <geometry>
        <mesh filename="package://ra6a/meshes/base_link.stl" scale="1.0 1.0 1.0"/>
      </geometry>
    </collision>
  </link>
  <link name="l1">
    <inertial>
      <origin xyz="-0.018341 -0.038699 -0.09919" rpy="0 0 0" />
      <mass value="2.4989" />
      <inertia ixx="0.013037" ixy="-0.0027249" ixz="0.001464" iyy="0.010527" iyz="0.0022131" izz="0.010986" />
    </inertial>
    <visual>
      <origin xyz="0 0 0" rpy="0 0 0" />
      <geometry>
        <mesh filename="package://ra6a/meshes/l1.stl" scale="1.0 1.0 1.0"/>
      </geometry>
      <material name="">
        <color rgba="0.79216 0.81961 0.93333 1" />
      </material>
    </visual>
    <collision>
      <origin xyz="0 0 0" rpy="0 0 0" />
      <geometry>
        <mesh filename="package://ra6a/meshes/l1.stl" scale="1.0 1.0 1.0" />
      </geometry>
    </collision>
  </link>
  <joint name="j1" type="revolute">
    <origin xyz="0.11229 -0.03609 0.1369" rpy="3.1416 0 1.5708" />
    <parent link="base_link" />
    <child link="l1" />
    <axis xyz="0 0 1" />
    <limit lower="-3.0979" upper="3.0979" effort="55.5" velocity="1.05" />
  </joint>
  <link name="l2">
    <inertial>
      <origin xyz="-0.074795 0.06129 -0.10126" rpy="0 0 0" />
      <mass value="3.5609" />
      <inertia ixx="0.021496" ixy="0.00028586" ixz="0.00088645" iyy="0.031862" iyz="0.0004388" izz="0.017196" />
    </inertial>
    <visual>
      <origin xyz="0 0 0" rpy="0 0 0" />
      <geometry>
        <mesh filename="package://ra6a/meshes/l2.stl" scale="1.0 1.0 1.0"/>
      </geometry>
      <material name="">
        <color rgba="1 1 1 1" />
      </material>
    </visual>
    <collision>
      <origin xyz="0 0 0" rpy="0 0 0" />
      <geometry>
        <mesh filename="package://ra6a/meshes/l2.stl" scale="1.0 1.0 1.0"/>
      </geometry>
    </collision>
  </link>
  <joint name="j2" type="revolute">
    <origin xyz="0.038867 -0.059201 -0.33764" rpy="0.93632 0 -0.23845" />
    <parent link="l1" />
    <child link="l2" />
    <axis xyz="1 0 0" />
    <limit lower="-1.5708" upper="1.8326" effort="110" velocity="1.05" />
  </joint>
  <link name="l3">
    <inertial>
      <origin xyz="-0.049486 0.00072803 0.094" rpy="0 0 0" />
      <mass value="3.1038" />
      <inertia ixx="0.013328" ixy="4.3048E-05" ixz="-8.438E-05" iyy="0.016047" iyz="0.00018895" izz="0.0094678" />
    </inertial>
    <visual>
      <origin xyz="0 0 0" rpy="0 0 0" />
      <geometry>
        <mesh filename="package://ra6a/meshes/l3.stl" scale="1.0 1.0 1.0"/>
      </geometry>
      <material name="">
        <color rgba="0.79608 0.82353 0.93725 1" />
      </material>
    </visual>
    <collision>
      <origin xyz="0 0 0" rpy="0 0 0" />
      <geometry>
        <mesh filename="package://ra6a/meshes/l3.stl" scale="1.0 1.0 1.0"/>
      </geometry>
    </collision>
  </link>
  <joint name="j3" type="revolute">
    <origin xyz="-0.051751 0.065262 -0.17987" rpy="-3.1182 0 -3.1416" />
    <parent link="l2" />
    <child link="l3" />
    <axis xyz="1 0 0" />
    <limit lower="-1.9634954" upper="1.9634954" effort="65" velocity="1.05" />
  </joint>
  <link name="l4">
    <inertial>
      <origin xyz="-0.0064465 0.00019408 0.054263" rpy="0 0 0" />
      <mass value="0.72283" />
      <inertia ixx="0.0016231" ixy="-3.7592E-06" ixz="-1.0915E-05" iyy="0.0031796" iyz="-1.091E-06" izz="0.0024777" />
    </inertial>
    <visual>
      <origin xyz="0 0 0" rpy="0 0 0" />
      <geometry>
        <mesh filename="package://ra6a/meshes/l4.stl" scale="1.0 1.0 1.0"/>
      </geometry>
      <material name="">
        <color rgba="0.79608 0.82353 0.93725 1" />
      </material>
    </visual>
    <collision>
      <origin xyz="0 0 0" rpy="0 0 0" />
      <geometry>
        <mesh filename="package://ra6a/meshes/l4.stl" scale="1.0 1.0 1.0"/>
      </geometry>
    </collision>
  </link>
  <joint name="j4" type="revolute">
    <origin xyz="5.5E-05 1.9679E-05 0.2525" rpy="0 0 -3.1366" />
    <parent link="l3" />
    <child link="l4" />
    <axis xyz="0 0 1" />
    <limit lower="-3.0979" upper="3.0979" effort="20" velocity="1.05" />
  </joint>
  <link name="l5">
    <inertial>
      <origin xyz="0.077494 0.00023934 0.047525" rpy="0 0 0" />
      <mass value="0.59888" />
      <inertia ixx="0.00051226" ixy="5.4361E-07" ixz="-2.0014E-05" iyy="0.00074482" iyz="-1.971E-07" izz="0.00065835" />
    </inertial>
    <visual>
      <origin xyz="0 0 0" rpy="0 0 0" />
      <geometry>
        <mesh filename="package://ra6a/meshes/l5.stl" scale="1.0 1.0 1.0"/>
      </geometry>
      <material name="">
        <color rgba="1 1 1 1" />
      </material>
    </visual>
    <collision>
      <origin xyz="0 0 0" rpy="0 0 0" />
      <geometry>
        <mesh filename="package://ra6a/meshes/l5.stl" scale="1.0 1.0 1.0"/>
      </geometry>
    </collision>
  </link>
  <joint name="j5" type="revolute">
    <origin xyz="-0.0435 -0.00031432 0.089001" rpy="-0.0057674 0 0" />
    <parent link="l4" />
    <child link="l5" />
    <axis xyz="1 0 0" />
    <limit lower="-2.26893" upper="2.26893" effort="7" velocity="1.05" />
  </joint>
  <link name="end_effector">
    <inertial>
      <origin xyz="1.0858E-08 3.2998E-06 -0.0020815" rpy="0 0 0" />
      <mass value="0.010728" />
      <inertia ixx="1.2754E-06" ixy="-6.705E-13" ixz="-1.0633E-12" iyy="1.9358E-06" iyz="-1.5271E-10" izz="2.32E-06" />
    </inertial>
    <visual>
      <origin xyz="0 0 0" rpy="0 0 0" />
      <geometry>
        <mesh filename="package://ra6a/meshes/end_effector.stl" scale="1.0 1.0 1.0"/>
      </geometry>
      <material name="">
        <color rgba="0.79216 0.81961 0.93333 1" />
      </material>
    </visual>
    <collision>
      <origin xyz="0 0 0" rpy="0 0 0" />
      <geometry>
        <mesh filename="package://ra6a/meshes/end_effector.stl" scale="1.0 1.0 1.0"/>
      </geometry>
    </collision>
  </link>
  <joint name="j6" type="revolute">
    <origin xyz="0.0435 0 0.1025" rpy="0 0 -1.5764" />
    <parent link="l5" />
    <child link="end_effector" />
    <axis xyz="0 0 1" />
    <limit lower="-3.0979" upper="3.0979" effort="1.8" velocity="1.05" />
  </joint>
</robot>

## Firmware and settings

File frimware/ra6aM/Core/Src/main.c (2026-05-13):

/**
  ******************************************************************************
  * @file           : main.c
  * @brief          : RA6A Robot Arm - AccelStepper Coordinated Motion
  ******************************************************************************
  * RX topic 101: position[6] float32 degrees = 24 bytes (plan-execute)
  * RX topic 107: position[6] + velocity[6] float32 deg(/s) = 48 bytes (teleop)
  * TX topic 102: position[6] float32 degrees = 24 bytes (20 Hz)
  * TX topic 103: 1 byte (homing done)
  * TX topic 104: 1 byte (motion done)
  *
  * Hold CONFIRM (PC10) at boot to skip homing.
  * Blue LED (PB7) ON after homing. Toggles on each command received.
  ******************************************************************************
  */

#include "main.h"
#include <math.h>
#include <string.h>
#include <stdint.h>
#include <stdlib.h>

/* ---- defines ---- */
#define NUM_JOINTS      6
#define FLASH_ADDR      0x080E0000UL
#define FLASH_MAGIC     0xA6A00001UL
#define DIR_NEGATIVE    GPIO_PIN_RESET
#define DIR_POSITIVE    GPIO_PIN_SET
#define TIMER_CLOCK_HZ  1000000UL
#define MIN_ARR         50UL
#define MAX_ARR         200000UL
#define TOPIC_CMD       101
#define TOPIC_STATE     102
#define TOPIC_HOMED     103
#define TOPIC_DONE      104
#define TOPIC_GRIPPER   105
#define TOPIC_STREAM    106
#define TOPIC_CMD_V     107
#define SYNC1           0xFF
#define SYNC2           0xFE
#define RX_BUF_SZ       256
#define JOG_STEPS       3
#define JOG_FRAC        0.08f
#define PULSE_US        5
#define MIN_SPEED       10.0f
#define LED_PORT        GPIOB
#define LED_PIN         GPIO_PIN_7
#define SERVO_PORT      GPIOB
#define SERVO_PIN       GPIO_PIN_8    /* D5 on Nucleo-144, TIM10_CH1 (AF3) */
#define SERVO_OPEN_DEG  26
#define SERVO_CLOSE_DEG 55

/* ---- types ---- */
typedef struct {
    GPIO_TypeDef* STEP_PORT;  uint16_t STEP_PIN;
    GPIO_TypeDef* DIR_PORT;   uint16_t DIR_PIN;
    GPIO_TypeDef* ENA_PORT;   uint16_t ENA_PIN;
    TIM_TypeDef*  TIM;
    volatile int32_t pos;
    volatile int32_t tgt;
    float max_spd;
    float accel;
    volatile float spd;
    volatile int8_t dir;
    volatile uint8_t run;
    volatile uint8_t vmode;
    uint32_t home_off;
} Motor;

typedef struct {
    uint32_t magic;
    uint8_t  cal;
    uint32_t off[NUM_JOINTS];
} Flash;

typedef enum {
    W_S1, W_S2, W_LL, W_LH, W_C1, W_TL, W_TH, W_PL, W_C2
} Parse;

/* ---- constants ---- */
static const uint32_t SPR[6] = { 5235, 15166, 7333, 4000, 3688, 1000 };
static const int8_t   INV[6] = { 1, 0, 1, 0, 1, 1 };
/*
 * Speed at 0.75 rad/s (50% of max). Accel = 1.5x speed (gentle ramp).
 * Original was 1.5 rad/s with 3x accel — too much inertia.
 */
static const float    MSPD[6] = { 625.0f, 1810.0f, 875.0f, 478.0f, 440.0f, 120.0f };
static const float    MACC[6] = { 940.0f, 2715.0f, 1315.0f, 716.0f, 660.0f, 180.0f };

/*
 * HARD JOINT LIMITS in degrees (from URDF).
 * STM32 will NEVER move past these regardless of commands received.
 */
static const float JMIN[6] = { -177.0f, -75.0f, -25.0f, -177.0f, -90.0f, -177.0f };
static const float JMAX[6] = {  177.0f,  97.0f, 205.0f,  177.0f,  90.0f,  177.0f };

/* ---- motors ---- */
static Motor M[6] = {
    { GPIOB, GPIO_PIN_5,  GPIOB, GPIO_PIN_3,  GPIOA, GPIO_PIN_4,  TIM1, 0,0, 0,0,0, 1,0,0, 0 },
    { GPIOB, GPIO_PIN_4,  GPIOB, GPIO_PIN_6,  GPIOB, GPIO_PIN_2,  TIM2, 0,0, 0,0,0, 1,0,0, 0 },
    { GPIOD, GPIO_PIN_13, GPIOD, GPIO_PIN_12, GPIOD, GPIO_PIN_11, TIM3, 0,0, 0,0,0, 1,0,0, 0 },
    { GPIOE, GPIO_PIN_2,  GPIOA, GPIO_PIN_0,  GPIOB, GPIO_PIN_0,  TIM4, 0,0, 0,0,0, 1,0,0, 0 },
    { GPIOE, GPIO_PIN_0,  GPIOE, GPIO_PIN_14, GPIOE, GPIO_PIN_12, TIM5, 0,0, 0,0,0, 1,0,0, 0 },
    { GPIOE, GPIO_PIN_10, GPIOE, GPIO_PIN_7,  GPIOE, GPIO_PIN_8,  TIM6, 0,0, 0,0,0, 1,0,0, 0 },
};

/* ---- buttons ---- */
#define BL_P GPIOC
#define BL_N GPIO_PIN_8
#define BR_P GPIOC
#define BR_N GPIO_PIN_9
#define BC_P GPIOC
#define BC_N GPIO_PIN_10

/* ---- rx state ---- */
static uint8_t rxbuf[RX_BUF_SZ];
static volatile uint16_t rxhead = 0;
static DMA_HandleTypeDef hdma;
static Parse    pstate = W_S1;
static uint16_t plen = 0, ptopic = 0, pidx = 0;
static uint8_t  ppay[64], pchk1 = 0, pchk2 = 0;

/* ---- command ---- */
static volatile uint8_t got_cmd = 0;
static volatile uint8_t got_grip = 0;
static volatile uint8_t grip_val = 0;
static volatile uint8_t got_stream = 0;
static float cmd_deg[6] = {0};
static float stream_deg[6] = {0};
static volatile uint8_t got_cmd_v = 0;
static float cmdv_deg[6] = {0};
static float cmdv_vel[6] = {0};

/* ---- prototypes ---- */
void SystemClock_Config(void);
static void init_gpio(void);
static void init_dma(void);
static void init_uart(void);
static void init_tim(TIM_TypeDef *t, IRQn_Type irq);
static void delay_us(uint32_t us);
static void dwt_init(void);
static int32_t d2s(float deg, int j);
static float s2d(int32_t s, int j);
static void enable_all(void);
static void init_servo(void);
static void servo_write(uint8_t angle);
static void gripper_open(void);
static void gripper_close(void);
static void tx_bytes(const uint8_t *d, uint16_t n);
static void rs_tx(uint16_t topic, const uint8_t *pay, uint16_t len);
static void tx_state(void);
static void tx_homed(void);
static void tx_done(void);
static void parse_byte(uint8_t b);
static void poll_rx(void);
static float ttm(float a, float v, int32_t d);
static void move_coord(const float deg[]);
static void update_targets(const float deg[]);
static void move_velocity(const float deg[], const float vel[]);
static void do_homing(void);
static void flash_save(void);

/* ============================================================
 *  MAIN
 * ============================================================ */

int main(void)
{
    HAL_Init();
    SystemClock_Config();
    init_gpio();
    init_dma();
    init_uart();
    init_tim(TIM1, TIM1_UP_TIM10_IRQn);
    init_tim(TIM2, TIM2_IRQn);
    init_tim(TIM3, TIM3_IRQn);
    init_tim(TIM4, TIM4_IRQn);
    init_tim(TIM5, TIM5_IRQn);
    init_tim(TIM6, TIM6_DAC_IRQn);
    dwt_init();
    init_servo();
    enable_all();

    /* Hold CONFIRM at boot = skip homing */
    HAL_Delay(200);
    if (HAL_GPIO_ReadPin(BC_P, BC_N) != GPIO_PIN_SET) {
        do_homing();
    }

    /* Blue LED ON = ready */
    HAL_GPIO_WritePin(LED_PORT, LED_PIN, GPIO_PIN_SET);
    gripper_open();  /* Start with gripper open */
    tx_homed();
    tx_state();

    uint32_t last_tx = HAL_GetTick();
    uint8_t was_moving = 0;

    while (1)
    {
        poll_rx();

        if (got_cmd) {
            got_cmd = 0;
            float p[6];
            __disable_irq();
            memcpy(p, (void *)cmd_deg, sizeof(p));
            __enable_irq();
            move_coord(p);
        }

        if (got_stream) {
            got_stream = 0;
            float p[6];
            __disable_irq();
            memcpy(p, (void *)stream_deg, sizeof(p));
            __enable_irq();
            update_targets(p);
        }

        if (got_cmd_v) {
            got_cmd_v = 0;
            float p[6], v[6];
            __disable_irq();
            memcpy(p, (void *)cmdv_deg, sizeof(p));
            memcpy(v, (void *)cmdv_vel, sizeof(v));
            __enable_irq();
            move_velocity(p, v);
        }

        if (got_grip) {
            got_grip = 0;
            servo_write(grip_val);  /* angle 0-180 directly */
        }

        /* Detect motion complete */
        uint8_t any = 0;
        for (int j = 0; j < 6; j++) if (M[j].run) { any = 1; break; }
        if (was_moving && !any) tx_done();
        was_moving = any;

        /* 20 Hz state feedback */
        uint32_t now = HAL_GetTick();
        if (now - last_tx >= 50) {
            tx_state();
            last_tx = now;
        }
    }
}

/* ============================================================
 *  CLOCK 180 MHz
 * ============================================================ */

void SystemClock_Config(void)
{
    RCC_OscInitTypeDef o = {0};
    RCC_ClkInitTypeDef c = {0};
    __HAL_RCC_PWR_CLK_ENABLE();
    __HAL_PWR_VOLTAGESCALING_CONFIG(PWR_REGULATOR_VOLTAGE_SCALE1);
    o.OscillatorType = RCC_OSCILLATORTYPE_HSE;
    o.HSEState = RCC_HSE_BYPASS;
    o.PLL.PLLState = RCC_PLL_ON;
    o.PLL.PLLSource = RCC_PLLSOURCE_HSE;
    o.PLL.PLLM = 4; o.PLL.PLLN = 180;
    o.PLL.PLLP = RCC_PLLP_DIV2; o.PLL.PLLQ = 7;
    if (HAL_RCC_OscConfig(&o) != HAL_OK) Error_Handler();
    if (HAL_PWREx_EnableOverDrive() != HAL_OK) Error_Handler();
    c.ClockType = RCC_CLOCKTYPE_HCLK|RCC_CLOCKTYPE_SYSCLK|RCC_CLOCKTYPE_PCLK1|RCC_CLOCKTYPE_PCLK2;
    c.SYSCLKSource = RCC_SYSCLKSOURCE_PLLCLK;
    c.AHBCLKDivider = RCC_SYSCLK_DIV1;
    c.APB1CLKDivider = RCC_HCLK_DIV4;
    c.APB2CLKDivider = RCC_HCLK_DIV2;
    if (HAL_RCC_ClockConfig(&c, FLASH_LATENCY_5) != HAL_OK) Error_Handler();
}

/* ============================================================
 *  GPIO
 * ============================================================ */

static void init_gpio(void)
{
    GPIO_InitTypeDef g = {0};
    __HAL_RCC_GPIOA_CLK_ENABLE();
    __HAL_RCC_GPIOB_CLK_ENABLE();
    __HAL_RCC_GPIOC_CLK_ENABLE();
    __HAL_RCC_GPIOD_CLK_ENABLE();
    __HAL_RCC_GPIOE_CLK_ENABLE();

    g.Mode = GPIO_MODE_OUTPUT_PP;
    g.Pull = GPIO_NOPULL;
    g.Speed = GPIO_SPEED_FREQ_HIGH;

    g.Pin = GPIO_PIN_0 | GPIO_PIN_4;
    HAL_GPIO_Init(GPIOA, &g);

    g.Pin = GPIO_PIN_0|GPIO_PIN_2|GPIO_PIN_3|GPIO_PIN_4|GPIO_PIN_5|GPIO_PIN_6|GPIO_PIN_7;
    HAL_GPIO_Init(GPIOB, &g);

    g.Pin = GPIO_PIN_11|GPIO_PIN_12|GPIO_PIN_13;
    HAL_GPIO_Init(GPIOD, &g);

    g.Pin = GPIO_PIN_0|GPIO_PIN_2|GPIO_PIN_7|GPIO_PIN_8|GPIO_PIN_10|GPIO_PIN_12|GPIO_PIN_14;
    HAL_GPIO_Init(GPIOE, &g);

    g.Pin = BL_N|BR_N|BC_N;
    g.Mode = GPIO_MODE_INPUT;
    g.Pull = GPIO_PULLDOWN;
    HAL_GPIO_Init(GPIOC, &g);

    /* Servo on PB8 — TIM10 CH1 hardware PWM (AF3) */
    g.Pin = SERVO_PIN;
    g.Mode = GPIO_MODE_AF_PP;
    g.Pull = GPIO_NOPULL;
    g.Speed = GPIO_SPEED_FREQ_HIGH;
    g.Alternate = 0x03;  /* AF3 = TIM8/9/10/11 family */
    HAL_GPIO_Init(SERVO_PORT, &g);

    for (int i = 0; i < 6; i++) {
        HAL_GPIO_WritePin(M[i].STEP_PORT, M[i].STEP_PIN, GPIO_PIN_RESET);
        HAL_GPIO_WritePin(M[i].DIR_PORT,  M[i].DIR_PIN,  GPIO_PIN_RESET);
        HAL_GPIO_WritePin(M[i].ENA_PORT,  M[i].ENA_PIN,  GPIO_PIN_SET);
    }
    HAL_GPIO_WritePin(LED_PORT, LED_PIN, GPIO_PIN_RESET);
}

/* ============================================================
 *  DMA + UART
 * ============================================================ */

static void init_dma(void)
{
    __HAL_RCC_DMA1_CLK_ENABLE();
    HAL_NVIC_SetPriority(DMA1_Stream1_IRQn, 0, 0);
    HAL_NVIC_EnableIRQ(DMA1_Stream1_IRQn);
}

static void init_uart(void)
{
    __HAL_RCC_USART3_CLK_ENABLE();
    __HAL_RCC_GPIOD_CLK_ENABLE();
    GPIO_InitTypeDef g = {0};
    g.Pin = GPIO_PIN_8|GPIO_PIN_9;
    g.Mode = GPIO_MODE_AF_PP;
    g.Pull = GPIO_NOPULL;
    g.Speed = GPIO_SPEED_FREQ_VERY_HIGH;
    g.Alternate = GPIO_AF7_USART3;
    HAL_GPIO_Init(GPIOD, &g);

    hdma.Instance = DMA1_Stream1;
    hdma.Init.Channel = DMA_CHANNEL_4;
    hdma.Init.Direction = DMA_PERIPH_TO_MEMORY;
    hdma.Init.PeriphInc = DMA_PINC_DISABLE;
    hdma.Init.MemInc = DMA_MINC_ENABLE;
    hdma.Init.PeriphDataAlignment = DMA_PDATAALIGN_BYTE;
    hdma.Init.MemDataAlignment = DMA_MDATAALIGN_BYTE;
    hdma.Init.Mode = DMA_CIRCULAR;
    hdma.Init.Priority = DMA_PRIORITY_MEDIUM;
    hdma.Init.FIFOMode = DMA_FIFOMODE_DISABLE;
    HAL_DMA_Init(&hdma);

    USART3->BRR = HAL_RCC_GetPCLK1Freq() / 115200;
    USART3->CR1 = USART_CR1_UE | USART_CR1_TE | USART_CR1_RE;
    USART3->CR3 = USART_CR3_DMAR;
    HAL_DMA_Start(&hdma, (uint32_t)&USART3->DR, (uint32_t)rxbuf, RX_BUF_SZ);
}

/* ============================================================
 *  TIMERS
 * ============================================================ */

static void init_tim(TIM_TypeDef *t, IRQn_Type irq)
{
    if      (t==TIM1) __HAL_RCC_TIM1_CLK_ENABLE();
    else if (t==TIM2) __HAL_RCC_TIM2_CLK_ENABLE();
    else if (t==TIM3) __HAL_RCC_TIM3_CLK_ENABLE();
    else if (t==TIM4) __HAL_RCC_TIM4_CLK_ENABLE();
    else if (t==TIM5) __HAL_RCC_TIM5_CLK_ENABLE();
    else if (t==TIM6) __HAL_RCC_TIM6_CLK_ENABLE();
    t->PSC = (t == TIM1) ? 179 : 89;
    t->ARR = 65535;
    t->DIER = TIM_DIER_UIE;
    t->CR1 = TIM_CR1_ARPE;
    HAL_NVIC_SetPriority(irq, 1, 0);
    HAL_NVIC_EnableIRQ(irq);
}

/* ============================================================
 *  UTILITIES
 * ============================================================ */

static void delay_us(uint32_t us)
{
    uint32_t c = us * (SystemCoreClock / 1000000UL);
    uint32_t s = DWT->CYCCNT;
    while ((DWT->CYCCNT - s) < c);
}

static void dwt_init(void)
{
    CoreDebug->DEMCR |= CoreDebug_DEMCR_TRCENA_Msk;
    DWT->CYCCNT = 0;
    DWT->CTRL |= DWT_CTRL_CYCCNTENA_Msk;
}

static int32_t d2s(float deg, int j)
{
    return (int32_t)roundf(deg * (float)SPR[j] / 360.0f);
}

static float s2d(int32_t s, int j)
{
    return (float)s * 360.0f / (float)SPR[j];
}

static void enable_all(void)
{
    for (int j = 0; j < 6; j++)
        HAL_GPIO_WritePin(M[j].ENA_PORT, M[j].ENA_PIN, GPIO_PIN_RESET);
}

/*
 * Clamp joint angles to hard limits. This is the LAST LINE OF DEFENSE.
 * No matter what command is received, joints will never exceed these limits.
 */
static void clamp_joints(float deg[])
{
    for (int j = 0; j < 6; j++) {
        if (deg[j] < JMIN[j]) deg[j] = JMIN[j];
        if (deg[j] > JMAX[j]) deg[j] = JMAX[j];
    }
}

/*
 * Hardware PWM servo on PB8 — TIM10 CH1.
 * 50Hz PWM, continuous. servo_write() just sets duty cycle (instant, non-blocking).
 * No more 300ms blocking loop.
 */
static void init_servo(void)
{
    __HAL_RCC_TIM10_CLK_ENABLE();
    /* TIM10 on APB2: 180MHz timer clock (APB2 div=2 → 90MHz, timers get 2x) */
    TIM10->PSC  = 179;        /* 180MHz / 180 = 1MHz tick */
    TIM10->ARR  = 19999;      /* 1MHz / 20000 = 50Hz period */
    TIM10->CCMR1 = (6 << 4)   /* OC1M = PWM mode 1 */
                 | TIM_CCMR1_OC1PE;  /* preload enable */
    TIM10->CCER = TIM_CCER_CC1E;     /* enable CH1 output */
    TIM10->CCR1 = 1500;       /* 90° default = 1500µs */
    TIM10->EGR  = TIM_EGR_UG; /* load shadow registers */
    /* NO DIER — no interrupts needed. Hardware does PWM autonomously. */
    TIM10->CR1  = TIM_CR1_ARPE | TIM_CR1_CEN;
}

static void servo_write(uint8_t angle)
{
    if (angle > 180) angle = 180;
    /* Pulse: 500µs (0°) to 2500µs (180°). CCR in µs at 1MHz tick. */
    TIM10->CCR1 = 500 + ((uint32_t)angle * 2000) / 180;
}

static void gripper_open(void)  { servo_write(SERVO_OPEN_DEG); }
static void gripper_close(void) { servo_write(SERVO_CLOSE_DEG); }

/* ============================================================
 *  UART TX + ROSSERIAL TX
 * ============================================================ */

static void tx_bytes(const uint8_t *d, uint16_t n)
{
    for (uint16_t i = 0; i < n; i++) {
        while (!(USART3->SR & USART_SR_TXE));
        USART3->DR = d[i];
    }
    while (!(USART3->SR & USART_SR_TC));
}

static void rs_tx(uint16_t topic, const uint8_t *pay, uint16_t len)
{
    uint8_t h[7];
    uint8_t ll = len & 0xFF, lh = (len >> 8) & 0xFF;
    h[0] = SYNC1; h[1] = SYNC2;
    h[2] = ll; h[3] = lh;
    h[4] = (255 - ((ll + lh) % 256)) & 0xFF;
    h[5] = topic & 0xFF;
    h[6] = (topic >> 8) & 0xFF;

    uint32_t cs = h[5] + h[6];
    for (uint16_t i = 0; i < len; i++) cs += pay[i];
    uint8_t c2 = (255 - (cs % 256)) & 0xFF;

    tx_bytes(h, 7);
    tx_bytes(pay, len);
    tx_bytes(&c2, 1);
}

static void tx_state(void)
{
    uint8_t buf[24];
    for (int j = 0; j < 6; j++) {
        float d = s2d(M[j].pos, j);
        memcpy(&buf[j*4], &d, 4);
    }
    rs_tx(TOPIC_STATE, buf, 24);
}

static void tx_homed(void) { uint8_t b = 1; rs_tx(TOPIC_HOMED, &b, 1); }
static void tx_done(void)  { uint8_t b = 1; rs_tx(TOPIC_DONE, &b, 1); }

/* ============================================================
 *  ROSSERIAL RX PARSER
 * ============================================================ */

static void parse_byte(uint8_t b)
{
    switch (pstate) {
    case W_S1: if (b == SYNC1) pstate = W_S2; break;
    case W_S2: pstate = (b == SYNC2) ? W_LL : W_S1; break;
    case W_LL: plen = b; pchk1 = b; pstate = W_LH; break;
    case W_LH: plen |= ((uint16_t)b << 8); pchk1 += b; pstate = W_C1; break;
    case W_C1:
        if (b == (uint8_t)((255 - (pchk1 % 256)) & 0xFF)) {
            pstate = W_TL; pchk2 = 0;
        } else {
            pstate = W_S1;
        }
        break;
    case W_TL: ptopic = b; pchk2 = b; pstate = W_TH; break;
    case W_TH:
        ptopic |= ((uint16_t)b << 8); pchk2 += b; pidx = 0;
        pstate = (plen > 0) ? W_PL : W_C2;
        break;
    case W_PL:
        if (pidx < sizeof(ppay)) ppay[pidx] = b;
        pchk2 += b; pidx++;
        if (pidx >= plen) pstate = W_C2;
        break;
    case W_C2:
        pstate = W_S1;
        if (b != (uint8_t)((255 - (pchk2 % 256)) & 0xFF)) break;

        if (ptopic == TOPIC_CMD && pidx == 24) {
            for (int j = 0; j < 6; j++)
                memcpy(&cmd_deg[j], &ppay[j * 4], 4);
            got_cmd = 1;
            HAL_GPIO_TogglePin(LED_PORT, LED_PIN);
        }
        else if (ptopic == TOPIC_GRIPPER && pidx == 1) {
            grip_val = ppay[0];
            got_grip = 1;
        }
        else if (ptopic == TOPIC_STREAM && pidx == 24) {
            for (int j = 0; j < 6; j++)
                memcpy(&stream_deg[j], &ppay[j * 4], 4);
            got_stream = 1;
        }
        else if (ptopic == TOPIC_CMD_V && pidx == 48) {
            for (int j = 0; j < 6; j++) {
                memcpy(&cmdv_deg[j], &ppay[j * 4], 4);
                memcpy(&cmdv_vel[j], &ppay[24 + j * 4], 4);
            }
            got_cmd_v = 1;
            HAL_GPIO_TogglePin(LED_PORT, LED_PIN);
        }
        break;
    default:
        pstate = W_S1;
    }
}

static void poll_rx(void)
{
    uint16_t dh = RX_BUF_SZ - DMA1_Stream1->NDTR;
    while (rxhead != dh) {
        parse_byte(rxbuf[rxhead]);
        rxhead = (rxhead + 1) % RX_BUF_SZ;
    }
}

/* ============================================================
 *  COORDINATED MOTION
 * ============================================================ */

static float ttm(float a, float v, int32_t dist)
{
    if (dist == 0) return 0.0f;
    float d = fabsf((float)dist);
    float ad = (v * v) / (2.0f * a);
    if (ad > d / 2.0f) ad = d / 2.0f;
    float vl = sqrtf(2.0f * a * ad);
    float at = vl / a;
    float vt = (d - 2.0f * ad) / vl;
    return 2.0f * at + vt;
}

static void move_coord(const float deg_in[])
{
    /* Clamp to hard limits */
    float deg[6];
    for (int j = 0; j < 6; j++) deg[j] = deg_in[j];
    clamp_joints(deg);

    int32_t delta[6];
    float times[6];

    for (int j = 0; j < 6; j++) {
        int32_t t = d2s(deg[j], j);
        delta[j] = t - M[j].pos;
        times[j] = ttm(MACC[j], MSPD[j], delta[j]);
    }

    float mt = 0.0f;
    for (int j = 0; j < 6; j++)
        if (times[j] > mt) mt = times[j];

    if (mt < 0.001f) return;

    for (int j = 0; j < 6; j++) {
        /* Stop timer before modifying state (prevent race with ISR) */
        M[j].TIM->CR1 &= ~TIM_CR1_CEN;
        M[j].TIM->SR   = ~TIM_SR_UIF;
        M[j].vmode = 0;

        if (delta[j] == 0) {
            M[j].tgt = M[j].pos;
            M[j].run = 0;
            M[j].spd = 0;
            continue;
        }

        float r = times[j] / mt;
        float sv = MSPD[j] * r;
        float sa = MACC[j] * r * r;
        if (sv > MSPD[j]) sv = MSPD[j];
        if (sa > MACC[j]) sa = MACC[j];
        if (sv < MIN_SPEED) sv = MIN_SPEED;
        if (sa < MIN_SPEED) sa = MIN_SPEED;

        M[j].max_spd = sv;
        M[j].accel = sa;
        M[j].tgt = d2s(deg[j], j);
        M[j].spd = MIN_SPEED;

        /* Direction */
        M[j].dir = (delta[j] > 0) ? 1 : -1;
        GPIO_PinState dp = (delta[j] > 0) ? DIR_POSITIVE : DIR_NEGATIVE;
        if (INV[j]) dp = (dp == DIR_POSITIVE) ? DIR_NEGATIVE : DIR_POSITIVE;
        HAL_GPIO_WritePin(M[j].DIR_PORT, M[j].DIR_PIN, dp);

        /* Start timer */
        uint32_t arr = (uint32_t)(TIMER_CLOCK_HZ / MIN_SPEED);
        if (arr > MAX_ARR) arr = MAX_ARR;
        M[j].TIM->ARR = arr;
        M[j].TIM->CNT = 0;
        M[j].TIM->EGR = TIM_EGR_UG;
        M[j].TIM->SR  = ~TIM_SR_UIF;
        M[j].TIM->CR1 |= TIM_CR1_CEN;
        M[j].run = 1;
    }
}

/* ============================================================
 *  STREAMING: update targets without resetting speed
 *  - If motor already running in same direction: just update target
 *  - If direction changes: update direction, keep speed
 *  - If motor stopped: start it from MIN_SPEED
 * ============================================================ */
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

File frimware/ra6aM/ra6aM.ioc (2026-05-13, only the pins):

Mcu.UserName=STM32F439ZITx
PA1.GPIO_Label=RMII_REF_CLK [LAN8742A-CZ-TR_REFCLK0]
PA1.Signal=ETH_REF_CLK
PA10.GPIO_Label=USB_ID
PA10.Signal=USB_OTG_FS_ID
PA11.GPIO_Label=USB_DM
PA11.Signal=USB_OTG_FS_DM
PA12.GPIO_Label=USB_DP
PA12.Signal=USB_OTG_FS_DP
PA13.GPIO_Label=TMS
PA13.Signal=SYS_JTMS-SWDIO
PA14.GPIO_Label=TCK
PA14.Signal=SYS_JTCK-SWCLK
PA2.GPIO_Label=RMII_MDIO [LAN8742A-CZ-TR_MDIO]
PA2.Signal=ETH_MDIO
PA7.GPIO_Label=RMII_CRS_DV [LAN8742A-CZ-TR_CRS_DV]
PA7.Signal=ETH_CRS_DV
PA8.GPIO_Label=USB_SOF [TP1]
PA8.Signal=USB_OTG_FS_SOF
PA9.GPIO_Label=USB_VBUS
PA9.Signal=USB_OTG_FS_VBUS
PB0.GPIO_Label=LD1 [Green]
PB0.Signal=GPIO_Output
PB13.GPIO_Label=RMII_TXD1 [LAN8742A-CZ-TR_TXD1]
PB13.Signal=ETH_TXD1
PB14.GPIO_Label=LD3 [Red]
PB14.Signal=GPIO_Output
PB7.GPIO_Label=LD2 [Blue]
PB7.Signal=GPIO_Output
PC1.GPIO_Label=RMII_MDC [LAN8742A-CZ-TR_MDC]
PC1.Signal=ETH_MDC
PC13.GPIO_Label=USER_Btn [B1]
PC13.Signal=GPXTI13
PC14/OSC32_IN.Signal=RCC_OSC32_IN
PC15/OSC32_OUT.Signal=RCC_OSC32_OUT
PC4.GPIO_Label=RMII_RXD0 [LAN8742A-CZ-TR_RXD0]
PC4.Signal=ETH_RXD0
PC5.GPIO_Label=RMII_RXD1 [LAN8742A-CZ-TR_RXD1]
PC5.Signal=ETH_RXD1
PD8.GPIO_Label=STLK_RX [STM32F103CBT6_PA3]
PD8.Signal=USART3_TX
PD9.GPIO_Label=STLK_TX [STM32F103CBT6_PA2]
PD9.Signal=USART3_RX
PG11.GPIO_Label=RMII_TX_EN [LAN8742A-CZ-TR_TXEN]
PG11.Signal=ETH_TX_EN
PG13.GPIO_Label=RMII_TXD0 [LAN8742A-CZ-TR_TXD0]
PG13.Signal=ETH_TXD0
PG6.GPIO_Label=USB_PowerSwitchOn [STMPS2151STR_EN]
PG6.Signal=GPIO_Output
PG7.GPIO_Label=USB_OverCurrent [STMPS2151STR_FAULT]
PG7.Signal=GPIO_Input
PH0/OSC_IN.GPIO_Label=MCO [STM32F103CBT6_PA8]
PH0/OSC_IN.Signal=RCC_OSC_IN
PH1/OSC_OUT.Signal=RCC_OSC_OUT

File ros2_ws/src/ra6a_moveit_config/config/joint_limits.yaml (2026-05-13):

# joint_limits.yaml allows the dynamics properties specified in the URDF to be overwritten or augmented as needed

# For beginners, we downscale velocity and acceleration limits.
# You can always specify higher scaling factors (<= 1.0) in your motion requests.  # Increase the values below to 1.0 to always move at maximum speed.
default_velocity_scaling_factor: 0.5
default_acceleration_scaling_factor: 0.5

# Specific joint properties can be changed with the keys [max_position, min_position, max_velocity, max_acceleration]
# Joint limits can be turned off with [has_velocity_limits, has_acceleration_limits]
joint_limits:
  j1:
    has_velocity_limits: true
    max_velocity: 0.75
    has_acceleration_limits: true
    max_acceleration: 0.5
  j2:
    has_velocity_limits: true
    max_velocity: 0.75
    has_acceleration_limits: true
    max_acceleration: 0.5
  j3:
    has_velocity_limits: true
    max_velocity: 0.75
    has_acceleration_limits: true
    max_acceleration: 0.5
  j4:
    has_velocity_limits: true
    max_velocity: 0.75
    has_acceleration_limits: true
    max_acceleration: 0.5
  j5:
    has_velocity_limits: true
    max_velocity: 0.75
    has_acceleration_limits: true
    max_acceleration: 0.5
  j6:
    has_velocity_limits: true
    max_velocity: 0.75
    has_acceleration_limits: true
    max_acceleration: 0.5

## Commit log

2026-05-15 Update J2 CAD, swap workspace image
    [j2-2.STEP]
2026-05-18 added assembly with part names dxf to help huide assembly
